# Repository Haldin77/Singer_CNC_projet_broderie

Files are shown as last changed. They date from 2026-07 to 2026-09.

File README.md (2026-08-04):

# Brodeuse CNC à partir d'une Singer en fonte

Conversion d'une machine à coudre Singer en fonte en brodeuse numérique : chariot X/Y sur mesure, axe Z motorisé pour l'entraînement de l'aiguille, contrôleur ESP32 sous FluidNC.

## L'idée qui structure le projet

La plupart des conversions DIY ([Embroiderino](https://gitlab.com/markol/embroiderino), [OpenEmbroidery](https://github.com/F33RNI/OpenEmbroidery)) gardent le moteur d'origine en boucle ouverte et doivent *suivre* la machine avec un capteur : l'électronique attend le signal « aiguille en haut » avant d'autoriser le mouvement du cadre.

**Ici, l'axe Z est piloté par le contrôleur.** On connaît donc l'angle de l'aiguille à tout instant en comptant les pas. Le capteur Hall ne sert plus qu'à l'indexation au démarrage et à la détection des pertes de pas.

Conséquence : un point de broderie s'écrit comme deux blocs G-code coordonnés.

```gcode
G1 X12.4 Y8.1 Z180    ; 1re demi-rotation : aiguille HAUTE, le cadre bouge
G1 Z360               ; 2e demi-rotation  : l'aiguille descend et pique
```

Z est un axe rotatif en degrés qui n'est jamais remis à zéro. C'est ce qui permet au planificateur de FluidNC de maintenir une rotation continue au lieu de s'arrêter à chaque point. **Aucun patch firmware n'est nécessaire** — ça tourne avec du FluidNC vanilla.

## État du projet

| Sous-ensemble | État |
|---|---|
| Post-processeur DST → G-code | ✅ fonctionnel, testé |
| Configuration FluidNC | ✅ écrite, non testée sur matériel |
| Schéma de câblage | ✅ [`docs/schema-cablage.svg`](docs/schema-cablage.svg) |
| Simulation Wokwi | ✅ brochage validé |
| **Mécanique** (portique X/Y + axe Z) | ✅ **montée et fonctionnelle** |
| Montage électrique | 🔧 en cours |
| Servo de tension du fil | 🔧 code prêt, servo à acheter |
| Alimentations | ✅ 48 V commandée + bloc 19,5 V récupéré |
| Détecteur de casse-fil | ❌ à concevoir |
| Pièces imprimées 3D | ❌ à modéliser |

## Architecture matérielle

| Axe | Moteur | Driver | Alimentation |
|---|---|---|---|
| Z (aiguille) | Nema 23, 3 N·m | DM542 | **48 V** — Mean Well LRS-100-48 |
| X | Nema 17 | DM320S | **19,5 V** — bloc HP récupéré |
| Y | **2 × Nema 17** (portique) | 2 × DM320S en parallèle | 19,5 V |
| A | Servo SG90/MG90S | PWM direct | 5 V |

Contrôleur : **ESP32-WROOM-32** + **74HCT245** (adaptation 3,3 V → 5 V pour les optocoupleurs des drivers). Pas de carte SD : les fichiers sont envoyés en **WiFi** via l'interface web de FluidNC.

## Organisation du dépôt

```
firmware/     Configuration FluidNC (YAML)
postproc/     Post-processeur broderie → G-code
  tests/      Fichiers DST de test
simulation/   Simulation Wokwi (validation du brochage)
gcode/        G-code généré
hardware/cad/ Pièces à imprimer (SolidWorks / STL)
docs/         Documentation détaillée + schéma de câblage
```

## Démarrage rapide

```bash
pip install pyembroidery
python3 postproc/dst2gcode.py motif.dst -o gcode/motif.nc --spm 400
```

Le script accepte DST, PES, EXP, JEF et les autres formats gérés par pyembroidery. Pour créer des motifs, [Ink/Stitch](https://inkstitch.org) (extension Inkscape, gratuite) exporte en DST.

## Chaîne complète

```
Inkscape + Ink/Stitch  →  motif.dst  →  dst2gcode.py  →  motif.nc  →  FluidNC (WiFi/SD)
```

## Documentation

- [**Montage électrique pas à pas**](docs/montage-electrique.md) — procédure avec test à chaque étape
- [Nomenclature et état des commandes](docs/nomenclature.md)
- [Câblage et brochage ESP32](docs/cablage.md)
- [Calculs et dimensionnement](docs/calculs.md)
- [Impression 3D](docs/impression-3d.md)
- [Mise en route et calibration](docs/mise-en-route.md)

## Avertissements

**Ne jamais mettre 48 V sur les DM320S.** Ils acceptent 12–38 V maximum et grillent au-delà. Les deux alimentations restent strictement séparées : 48 V uniquement vers le DM542, 19,5 V vers les trois DM320S. Seules les **masses** sont communes.

**Le pied à repriser n'est pas optionnel.** Avec un pied normal baissé, le tissu ne peut pas se déplacer. Relevé, le tissu remonte avec l'aiguille et les points sautent systématiquement. Il faut un pied à ressort qui suit la barre à aiguille, et les griffes d'entraînement abaissées.

## Licence

MIT — voir [LICENSE](LICENSE).

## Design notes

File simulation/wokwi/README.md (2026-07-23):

# Simulation Wokwi

Simulation du câblage logique de la brodeuse, avec un **vrai ESP32**, pour vérifier le brochage avant de toucher au matériel réel.

## Ouvrir la simulation

1. Aller sur [wokwi.com](https://wokwi.com) et créer un nouveau projet **ESP32 (Arduino)**
2. Remplacer le contenu de l'onglet `diagram.json` par celui de ce dossier
3. Remplacer le contenu de `sketch.ino` par celui de ce dossier
4. Cliquer sur ▶ pour lancer

Le moniteur série affiche l'état des quatre capteurs. Les trois moteurs tournent. Appuie sur les boutons pour simuler un capteur déclenché.

## Ce que la simulation représente fidèlement

- **ESP32** sur les mêmes GPIO de sortie que `firmware/fluidnc-config.yaml`
- Les **3 axes** (Z, X, Y) avec leurs signaux STEP / DIR et l'ENABLE partagé
- Les **4 entrées** capteur : fins de course X/Y, index Hall, casse-fil

## Ce qui diffère du montage réel — à garder en tête

| Simulation Wokwi | Machine réelle |
|---|---|
| Driver **A4988** | Driver **DM542 / DM320S** (Wokwi n'a pas ces modèles) |
| Pas de 74HCT245 | 74HCT245 obligatoire (décalage 3,3 V → 5 V) |
| Alimentation unique 5 V | **48 V** (Z) + **24 V** (X/Y) séparées |
| Code Arduino de test | **FluidNC** en production |

La simulation valide la **logique** (quel GPIO fait quoi), pas la **puissance**. Les A4988 remplacent les vrais drivers uniquement parce qu'ils partagent la même interface STEP/DIR/ENABLE.

## ⚠️ La leçon de cette simulation : le choix des pins d'entrée

La première version utilisait les **GPIO 34, 35, 36 et 39** pour les capteurs. Ce sont des pins en **entrée seule, sans pull-up interne** : ils flottent, et donnaient des lectures fantômes (un capteur à 0 sans qu'on l'ait touché). La directive `:pu` sur ces broches dans le YAML FluidNC est sans effet côté matériel.

**Deux façons de régler ça sur la vraie carte :**

1. **Pins à pull-up interne** (4, 21, 22, 32…) + `INPUT_PULLUP` — c'est le choix de cette simulation. Zéro composant externe, le plus simple.
2. **Garder 34-39** + résistances de tirage externes de 10 kΩ vers 3,3 V. Utile si on manque de pins ; souvent inutile car les modules capteurs (KY-003, cartes de fin de course) embarquent déjà leur pull-up.

👉 **Décision à reporter dans `firmware/fluidnc-config.yaml` et `docs/cablage.md`** : soit déplacer les entrées vers des pins à pull-up interne, soit assumer les résistances externes sur 34-39.

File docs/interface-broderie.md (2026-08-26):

# Interface broderie

Charger une image, la voir se transformer en points, l'envoyer à la machine et la broder — sans taper une seule commande.

## Lancer

```
cd interface
py -m pip install -r requirements.txt      (la première fois seulement)
py serveur.py
```

Puis `http://localhost:8080`. Depuis un téléphone ou une tablette sur le même réseau, remplace `localhost` par l'IP du PC.

Contrairement au mode couture, **cette interface a besoin d'un ordinateur** : le traitement d'image ne tient pas dans un ESP32. Le PC ne fait que préparer le fichier ; une fois la broderie lancée, il peut être éteint, la machine travaille seule depuis sa mémoire.

## Le déroulé

**1 · L'image.** Glisse un fichier dans la zone de dépôt.

**2 · Les réglages.** Taille visée, rendu, seuil de noir. Les réglages fins sont repliés — les valeurs par défaut conviennent dans la plupart des cas.

**3 · L'aperçu.** Le tracé réel des points : contour en bleu, remplissage en vert, sauts en pointillé orange. Le rectangle est ton champ de broderie. C'est ici qu'on juge, pas sur l'image de départ.

**4 · Broder.** Le bouton envoie le fichier dans la mémoire de la carte, fait le homing des trois axes, pose l'origine au centre du cadre et lance. Aucune coordonnée à saisir.

## Ce que la conversion sait faire, et ce qu'elle ne sait pas

Le moteur **binarise** l'image : chaque pixel est brodé ou ne l'est pas.

Sur un **logo, un dessin au trait, une silhouette, du texte**, c'est exactement ce qu'il faut. Les formes sont extraites, les trous respectés — l'intérieur d'un « O » reste vide — et chaque forme est remplie séparément.

Sur une **photographie**, tous les dégradés disparaissent et il ne reste qu'une tache informe. Rendre une photo demanderait des hachures de densité variable et un ordonnancement bien plus fin. Les logiciels commerciaux à plusieurs centaines d'euros s'y attellent avec des résultats inégaux.

## Les arrêts pendant la broderie

La machine s'arrête toute seule à plusieurs moments. Ce n'est pas une panne : chaque arrêt attend un geste de ta part, et tu reprends avec `~`.

| Quand | Ce que tu fais |
|---|---|
| Au premier point | tu remontes le fil de canette **à cet endroit**, tu tiens les deux fils vers l'arrière |
| Avant un saut de plus de 20 mm | tu **lèves le pied** |
| Juste après le saut | tu **rebaisses le pied** |
| À la fin | tu lèves le pied, puis tu dégages le cadre |

Le releveur de pied est manuel sur cette machine, et c'est lui qui écarte les disques de tension. Un long déplacement pied baissé tire sur le fil : il casse, ou il fronce le tissu.

Ces pauses disparaîtront quand le servo de débrayage (axe A) sera installé — c'est exactement le geste qu'il est censé automatiser.

Pour changer le seuil, ou les supprimer, voir `pause_saut_mm` dans `postproc/dst2gcode.py`.

### Le compteur de pauses

L'interface affiche le nombre de pauses que le motif imposera, à côté du nombre de points. C'est le chiffre à surveiller : il mesure le travail manuel, pas le travail de la machine. Au-delà de six, il vire à l'orange.

### Réduire les sauts

Le réglage **« relier les trajets distants de moins de X mm »** décide entre broder une liaison et sauter. Une liaison coûte quelques points, invisibles sous le remplissage ; un saut peut coûter une manipulation.

La liaison n'est acceptée que si le chemin **reste dans la matière** — sinon elle se verrait sur le tissu nu, et la machine saute.

Effet mesuré sur le mot SINGER en 120 mm :

| Distance de liaison | Trajets | Points |
|---|---|---|
| 0 mm — que des sauts | 136 | 2286 |
| 3 mm | 29 | 1971 |
| **5 mm — défaut** | **25** | **1967** |
| 8 mm | 24 | 1967 |

Cent trente-six trajets ramenés à vingt-cinq, **et** trois cents points de moins : les liaisons brodées remplacent des sauts qu'il fallait de toute façon rejoindre.

Au-delà de 5 mm le gain s'épuise, parce que les trajets encore séparés le sont par du vide, et le contrôle « reste dans la matière » refuse alors la liaison.

### Traverser en brodant plutôt que sauter

C'est le réglage qui supprime réellement les pauses.

Au lieu de **sauter** d'une zone à l'autre — aiguille en l'air, cadre qui file, fil tiré contre les disques de tension — la machine **y va en brodant**. Le fil est alors consommé par le releveur comme pour n'importe quel point : plus aucune traction, donc plus besoin de lever le pied.

Le prix, ce sont des fils tendus à couper à la fin. Mais **un saut en laissait déjà un**. La seule différence, c'est qu'il est maintenant piqué dans le tissu — et encadré par deux nœuds d'arrêt, donc le couper ne défait rien.

Sur SINGER en 120 mm :

| Traversée brodée jusqu'à | Points | Pauses | Fils à couper |
|---|---|---|---|
| 0 mm — que des sauts | 1983 | 4 | 0 |
| 15 mm | 2095 | 4 | 22 |
| **30 mm — défaut** | **2131** | **1** | **28** |
| 45 mm | 2138 | 0 | 29 |

Quatre pauses ramenées à une, pour 7 % de points en plus. À 45 mm, plus aucune pause.

Pourquoi les lettres produisent tant de trajets, au passage : une ligne horizontale traverse un `N` **trois fois** — montant gauche, diagonale, montant droit. Le `S`, le `E` et le `G` font pareil. Sur ce mot, 24 trajets de remplissage pour 6 lettres, et 7 contours parce que le `R` a un intérieur.

## Les nœuds d'arrêt

Avant chaque traversée, avant chaque saut et à la fin du motif, la machine pose un **petit zigzag** : trois points qui reculent d'un millimètre en se décalant d'un demi-millimètre alternativement de chaque côté, puis retour au point de départ. Quatre points en tout.

**Pourquoi un zigzag et pas un aller-retour.** Repasser exactement sur la même ligne fait retomber l'aiguille dans les mêmes trous. Le fil ne se bloque pas, il coulisse dans un trou agrandi, et le tissu s'affaiblit à cet endroit. En décalant, chaque point perce du tissu neuf et les fils se croisent — c'est le croisement qui tient, pas la répétition.

Mesuré sur un fichier réel, l'écart entre deux pénétrations successives d'un nœud est d'environ **1 mm**. Aucune ne retombe dans la précédente.

Ces valeurs — 3 points, 1 mm de long, 0,5 mm de large — sont celles des logiciels de numérisation du commerce. Réglables par `points_arret`, `longueur_arret_mm` et `largeur_arret_mm`.

**Le test qui tranche**, sur une chute : brode un petit motif, coupe les fils de traversée, puis tire franchement sur un bord. Si ça bouge, augmente `points_arret` à 4 ou `largeur_arret_mm` à 0,7.

## Le point de bourdon et les traits fins

C'est ce qui sépare un rendu amateur d'un rendu professionnel.

**Le problème.** Un trait de 1 mm rempli par des rangées parallèles donne trois rangées baveuses qui ne ressemblent plus au trait. C'est ce qui empâtait les logos au trait en petit format.

**Ce que font les professionnels.** Ils ne remplissent pas un trait fin : ils en prennent **l'axe** et le brodent en **point de bourdon** — un zigzag serré perpendiculaire au tracé, qui forme un ruban net et brillant.

La chaîne est donc :

```
masque → largeur locale → traits fins / masses pleines
                             ↓              ↓
                        squelette      remplissage
                             ↓              ↓
                          bourdon        contour
```

Le découpage se fait **à l'intérieur d'une même forme**, et c'est essentiel. Un logo est presque toujours d'un seul tenant : les contours au trait touchent les aplats. Classer la forme entière dans une famille faisait partir tout le dessin en bourdon, aplats compris — qui ressortaient confus. Le seuil ne donnait alors que deux résultats : une petite partie arbitraire en bourdon, ou la totalité.

La séparation se fait par **ouverture morphologique** : érosion puis dilatation par un disque du rayon voulu. Ne survivent que les endroits où ce disque tient entièrement — c'est exactement la définition d'une zone large. Le reste est du trait.

C'est ce que font les brodeurs professionnels : bourdon sur les traits, remplissage sur les aplats, sur la même pièce.

Vérifié sur un logo mixte d'un seul tenant — cadre fin, tête au trait, oreille pleine, rond plein, texte :

| | Résultat |
|---|---|
| Part en remplissage | 38 % |
| Part en bourdon | 62 % |
| Points | 2521 au lieu de 4394 |

Le ruban **épouse la largeur réelle du trait**, bornée entre 1,2 et 7 mm.

Mesuré sur un logo au trait à 160 mm :

| | Points | Durée |
|---|---|---|
| Remplissage seul | 3748 | 15,0 min |
| Avec bourdon | **2346** | **9,4 min** |

Plus net **et** plus rapide.

### Détails d'implémentation qui ont demandé du soin

**L'amincissement** est un Zhang-Suen écrit à la main : `cv2.ximgproc.thinning` n'existe que dans opencv-contrib, et scikit-image serait une dépendance de plus pour quarante lignes.

**Le traçage du squelette** ne compte pas les voisins mais les **transitions vide→matière** autour de chaque pixel. Dans une ligne d'un pixel en connexité 8, une marche d'escalier donne trois voisins à un pixel parfaitement ordinaire — compter ainsi fragmentait un simple anneau en trente-cinq morceaux.

**L'élagage** retire les barbules, ces courtes branches parasites que fait pousser l'amincissement sur le moindre bord irrégulier.

**Les tangentes sont lissées** sur un voisinage : sans cela la perpendiculaire bascule dans les angles et le ruban se vrille.

## La sous-couche

Une passe légère **avant** le remplissage : un contour en retrait de 0,7 mm, en point simple. Elle solidarise le tissu et l'entoilage et donne au remplissage une assise.

Sans elle, le remplissage tire sur un tissu libre — c'est la première cause de fronçage. Tous les motifs professionnels en ont une.

Les bourdons reçoivent la leur : une ligne centrale qui empêche le ruban de s'enfoncer et lui donne du relief.

L'ordre de broderie est celui du métier : **sous-couche, remplissage, bourdon, contour**.

## La compensation d'étirement

Le fil se contracte en se tendant et resserre la matière : une forme brodée sort plus étroite que dessinée. Les rubans sont élargis de 0,2 mm par défaut pour compenser, comme le font les logiciels du commerce.

## Le plancher physique

En dessous de **1,2 mm**, un trait ne peut pas exister : l'aiguille repique dans le trou précédent et **découpe le tissu** au lieu de le broder.

Deux mécanismes en découlent :

**L'épaississement.** Les traits sous ce minimum sont amenés à la largeur brodable, plutôt que de se désagréger. Seules les zones réellement trop fines sont dilatées.

**L'avertissement.** L'interface prévient quand des formes **fusionnent** en étant épaissies — elles étaient séparées de moins que la largeur minimale. C'est ce qui transforme un texte fin en pâte, et aucun réglage ne le rattrape : il faut agrandir le motif.

## Les réglages qui comptent

**Seuil de noir.** Laissé en automatique, il applique la méthode d'Otsu, qui se débrouille bien sur un dessin propre. Sur une image délavée ou photographiée de travers, décoche et déplace le curseur en regardant l'aperçu.

**Inverser.** Par défaut on brode ce qui est sombre. Un logo blanc sur fond noir demande cette case.

**Contour seul** donne un trait fin et un fichier dix fois plus léger. C'est le bon choix pour un premier essai sur un motif nouveau : quelques minutes au lieu d'une heure, et on voit tout de suite si la taille et le placement sont bons.

**Écartement du remplissage.** 0,45 mm donne un aplat dense. Monter à 0,8 divise le nombre de points par deux et laisse voir le tissu — parfois joli, souvent pas.

**Contour en triple passage.** Trois allers-retours sur le contour, ce qui triple son épaisseur apparente. C'est le « triple point » des brodeuses du commerce, et la façon la plus simple d'obtenir un trait visible sans calculer un point de bourdon.

## Les deux limites à surveiller

L'interface prévient d'elle-même, mais autant les connaître.

**La mémoire de l'ESP32.** C'est la contrainte dominante, et elle a demandé un travail à part — voir [Tenir dans la mémoire de l'ESP32](taille-fichiers.md). Le G-code est désormais écrit sous forme compacte, ce qui divise sa taille par deux. Ordres de grandeur, pour le mot SINGER :

| | Points | Taille |
|---|---|---|
| 120 mm, contour et remplissage | 1750 | 55 ko |
| 120 mm, écartement 1 mm | 1121 | 35 ko |
| 60 mm, contour et remplissage | 601 | 19 ko |
| 120 mm, contour seul | 663 | 20 ko |

**Le temps.** À 250 points/min, deux mille points font huit minutes. Un motif dense de quinze mille points fait une heure, pendant laquelle rien ne doit bouger.

## Si le téléversement automatique échoue

Le bouton **Télécharger le .nc** récupère le fichier. Tu le déposes ensuite dans le Flash Filesystem par le WebUI, comme tu l'as fait pour le YAML, puis tu le lances avec :

```
$LocalFS/Run=/motif.nc
```

Le fichier est de toute façon toujours écrit dans le dossier `gcode/` du projet.

## En ligne de commande

Tout le moteur est utilisable sans interface :

```
py postproc/image2points.py logo.png -o logo.nc --apercu logo.svg --largeur 100
```

`--mode contour` · `--seuil 140` · `--inverser` · `--espacement 0.8` · `--point 2.5` · `--spm 250`

## Comment c'est fait

```
image  →  seuillage  →  formes connexes
                              ├── contours  (OpenCV, simplifiés, triple passage)
                              └── remplissage (va-et-vient par forme)
                                        ↓
                              rééchantillonnage à la longueur de point
                                        ↓
                              ordonnancement au plus proche voisin
                                        ↓
                              dst2gcode.convert_paths()  →  G-code
```

La dernière étape réutilise **exactement le même émetteur** que pour les fichiers DST. Les demi-rotations de Z, le découpage des points trop longs, la remise à zéro de l'angle cumulé et les bornes du cadre sont donc traités de façon identique, quelle que soit la provenance du motif. Une correction à cet endroit profite aux deux chaînes.

Deux détails valent d'être signalés, parce qu'ils ont demandé une correction :

**Chaque forme est remplie séparément.** Sans ce découpage, le va-et-vient sautait d'une lettre à l'autre à chaque ligne — près de quatre cents sauts sur le mot SINGER au lieu de cent trente.

**Les liaisons entre lignes sont vérifiées.** Une liaison qui sortirait de la forme est refusée, et remplacée par un saut. C'est ce qui empêche le remplissage de traverser l'espace entre deux lettres, ou le trou d'un « O ».

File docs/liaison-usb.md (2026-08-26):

# Liaison USB et pédale progressive

Le WiFi sort de la boucle de commande. Le PC pilote la machine par un câble USB, et lit la pédale par un second.

```
pédale → potentiomètre → Arduino Uno ─USB→ PC ─USB→ ESP32 → drivers → machine
```

## Ce que ça règle d'un coup

| Problème | Pourquoi il disparaît |
|---|---|
| 44 ko de mémoire | le G-code reste sur le PC et part ligne par ligne |
| Déconnexions WiFi | le WiFi n'est plus dans la boucle de commande |
| Homing capricieux | plus d'émission radio soutenue pendant les commandes |
| Pas de pédale progressive | le PC lit le potentiomètre via l'Uno |

## Câblage du potentiomètre

Potentiomètre linéaire **10 kΩ**, solidaire mécaniquement de la course de la pédale.

| Borne | Vers |
|---|---|
| extrémité 1 | `5V` de l'Uno |
| curseur (milieu) | `A0` |
| extrémité 3 | `GND` |

Le 5 V ne pose aucun problème ici : l'ADC de l'Uno est prévu pour. C'est sur l'ESP32 qu'il serait destructeur.

> ⚠️ La pédale Singer d'origine commute du **230 V**. Elle doit être totalement déconnectée du secteur. Seul le potentiomètre, entraîné par sa course, est relié à l'Uno.

## Téléverser le croquis

Ouvre `pedale/pedale.ino` dans l'IDE Arduino, choisis la carte **Arduino Uno** et son port, puis téléverse.

Pour vérifier : ouvre le moniteur série à **115200 bauds**. Tu dois voir `PING` chaque seconde, et des lignes `P0` à `P100` quand tu bouges la pédale.

## Ce que le croquis fait

**Zone morte en début de course** — un potentiomètre ne revient jamais exactement à zéro, et une pédale au repos ne doit rien déclencher.

**Lissage** — le câble de la pédale passe près des drivers, qui rayonnent. Sans filtre, la consigne tremblerait en permanence.

**Un `PING` chaque seconde**, même à l'arrêt. C'est le cœur de la sécurité : il prouve que la pédale est toujours là. Si le PC cesse de le recevoir — câble débranché, Uno planté — il arrête la machine. Sans ce battement, une pédale muette serait indiscernable d'une pédale au repos.

**Le retour à zéro est transmis sans filtre.** C'est un ordre d'arrêt : il ne doit jamais être retenu par une hystérésis.

## Réponse de la pédale

Quadratique, comme sur une vraie machine : le début de course est fin — c'est là qu'on pose ses points un par un — et la fin de course monte vite.

| Enfoncement | Cadence |
|---|---|
| 3 % | 20 points/min |
| 30 % | 49 |
| 50 % | 109 |
| 70 % | 201 |
| 100 % | 400 |

Une réponse linéaire rendrait la machine impilotable au ralenti. Les constantes sont en haut de `interface/couture_pedale.py`.

## Le rythme d'envoi de la pédale

C'est le point qui a demandé deux corrections, et il mérite d'être compris.

**FluidNC répond `ok` dès qu'il a *planifié* un mouvement, pas quand il l'a exécuté.** Se caler sur les accusés de réception remplissait donc son planificateur de seize mouvements d'avance. Deux conséquences visibles : la machine continuait plusieurs secondes après le relâchement de la pédale, et elle cousait au ralenti — chaque mouvement décélérait à zéro faute du suivant prêt à temps.

Deuxième piège, plus subtil : envoyer « à 80 % de la durée d'un point » revient à envoyer **25 % plus vite que la machine ne consomme**. Le planificateur se remplit alors progressivement, et le délai revient au bout d'une minute de couture.

La solution est de raisonner en **avance de phase** : on garde un horizon — l'instant où tout ce qui est commandé sera terminé — et on n'envoie le point suivant que si cet horizon est à moins de 0,2 seconde. Le débit moyen se cale exactement sur la cadence, sans réglage.

Mesuré contre une machine simulée qui accuse vite et exécute au rythme réel :

| Pédale | Cadence visée | Cadence mesurée |
|---|---|---|
| 30 % | 49 pts/min | **49** |
| 60 % | 151 | **151** |
| 100 % | 400 | **400** |

Avance jamais supérieure à **1,5 point**. Au relâchement : **0 point envoyé de plus**, arrêt effectif en **0,21 s** — le temps de finir le point en cours, aiguille ressortie. C'est exactement le comportement d'une machine à coudre.

## Le contrôle de flux

L'envoi se fait par **comptage de caractères** : on garde en vol juste assez de lignes pour remplir le tampon de réception de la carte — 127 octets — sans jamais le déborder.

C'est supérieur à l'envoi « une ligne, un ok » : le tampon reste alimenté, donc la machine ne marque pas de micro-arrêt entre les points. Mesuré sur le banc : **119 octets au maximum sur 127**, jamais dépassé.

## Sécurité

**En broderie**, si l'envoi s'interrompt, la machine s'arrête faute de lignes. Rien ne part tout seul.

**En couture**, l'arbre avance par salves de deux points, chacune lancée à la vitesse lue sur la pédale à cet instant. Si quoi que ce soit s'interrompt, la machine termine sa salve et s'arrête. Elle n'attend **aucun** ordre d'arrêt qui pourrait ne jamais arriver — c'est un homme-mort par construction.

## Le banc d'essai

```
cd interface
python tests/test_liaison.py
```

Il crée un faux FluidNC et un faux Arduino sur des ports virtuels, et fait tourner le vrai code contre eux. Aucun matériel nécessaire.

Il vérifie que le tampon ne déborde jamais, que toutes les lignes arrivent dans l'ordre, qu'un `M0` suspend bien l'envoi jusqu'à la reprise, que pause et annulation passent en temps réel hors file d'attente, et qu'une pédale muette rend zéro.

Le faux firmware utilise **deux threads**, comme le vrai : un pour la lecture, un pour l'exécution. Un simulateur mono-thread se bloque sur le `M0` et ne voit jamais le `~` censé le débloquer — ce qui illustre précisément pourquoi le vrai firmware traite les caractères temps réel à part.

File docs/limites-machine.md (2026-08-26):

# Limites de course — mesures et champ de broderie

Mesuré le 5 août 2026, après validation du homing des trois axes.

## Méthode

Homing complet, puis `soft_limits` désactivé temporairement, puis avance par paliers décroissants jusqu'à la butée mécanique. Position lue avec `?`.

```
$H
$/axes/x/soft_limits=false
$/axes/y/soft_limits=false
$J=G91 X20 F500      (répété, puis X5, puis X1)
?
```

## Résultats

| Axe | Butée atteinte | Marge retirée | `max_travel_mm` |
|---|---|---|---|
| X | 172,000 mm | 3 mm | **169,000** |
| Y | 121,000 mm | 3 mm | **118,000** |
| Z | rotatif | — | 720,000 (garde-fou de homing seulement) |

La marge de 3 mm évite que le chariot vienne taper la structure sur une accumulation d'erreurs ou un léger décalage du capteur d'origine.

## Dégagements après homing (`pulloff_mm`)

| Axe | Capteur | `pulloff_mm` | Pourquoi |
|---|---|---|---|
| X | microrupteur à levier | 2,000 | valeur d'origine, jamais mise en défaut |
| Y | microrupteur à levier | **5,000** | 2 mm laissaient le levier enfoncé → `ALARM:8` |
| Z | Hall A3144 + aimant | **10,000** (degrés) | 5° laissaient l'aimant dans le champ → `ALARM:8` |

`ALARM:8 Homing Fail Pulloff` signifie toujours la même chose : après le dégagement, le capteur est encore actionné. La réponse est d'augmenter cette valeur, jamais de toucher aux vitesses.

Sur Z, augmenter le dégagement **ne décale pas la phase de l'aiguille** : le zéro machine reste ancré sur le déclenchement du capteur, et les `Z180` / `Z360` du G-code sont des positions absolues.

## Ce que ça change

Le champ utile est de **169 × 118 mm**. C'est **Y qui bride la machine**, et l'écart avec l'hypothèse de départ est important : on avait tablé sur 180 mm en Y, il y en a 121.

Conséquence directe : **le cadre Brother SA444 (130 × 180) ne rentre pas**, ni dans un sens ni dans l'autre. En le tournant de 90°, il faudrait 180 mm en X et on n'en a que 169.

Le post-processeur a donc été recalé sur **165 × 114 mm** (`--hoop`), soit le champ mesuré moins 2 mm de chaque côté. Cela correspond à un cadre du commerce de type 160 × 110, très courant.

## Si tu veux récupérer de la course en Y

Trois pistes, par ordre de gain :

1. **Repositionner le microrupteur d'origine Y.** S'il est monté en retrait, chaque millimètre récupéré est un millimètre de champ. Vérifie aussi que le `pulloff_mm` de 5 mm n'est pas surdimensionné une fois le capteur bien placé.
2. **Vérifier ce qui limite mécaniquement l'autre extrémité.** Une équerre, un passage de câble ou une vis dépassant coûtent parfois 10 à 15 mm pour rien.
3. **Rallonger le rail Y.** C'est le seul vrai gain, mais cela suppose de refaire la traverse.

## Z : pourquoi 720 et pas 10 000 000

`soft_limits` est à `false` sur Z, donc `max_travel_mm` ne limite pas la rotation de l'arbre — l'axe peut tourner indéfiniment pendant la broderie.

Cette valeur sert uniquement de **distance maximale de recherche pendant le homing**. Avec 720° (deux tours d'arbre), si l'aimant passe devant le capteur Hall sans être détecté, FluidNC lève une alarme au bout de deux tours. Avec l'ancienne valeur, l'arbre aurait tourné des heures.

## Vérification

Après téléversement et `$Bye` :

```
$H
$J=G91 X500 F500
```

Doit être refusé (`error:15`) ou tronqué à la limite. Idem en Y.

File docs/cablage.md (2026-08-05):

# Câblage et brochage

## Les schémas

Quatre schémas, un par sous-ensemble. Chacun tient sur un écran et se lit sans se perdre dans les fils.

| Schéma | Contenu |
|---|---|
| [1 · Alimentations](schema-1-alimentations.svg) | arrivée 230 V, interrupteur bipolaire, fusible, terre de protection, les trois alimentations, le condensateur |
| [2 · ESP32 → 74HCT245](schema-2-logique.svg) | brochage réel du boîtier DIP-20, entrées A, sorties B, et les trois broches de service qu'on oublie |
| [3 · Drivers et moteurs](schema-3-puissance.svg) | les quatre drivers borne par borne, et le raccordement des bobines |
| [4 · Capteurs](schema-4-capteurs.svg) | principe du pull-up interne, fins de course, arrêt d'urgence, capteurs Hall, servo |

Et la [**table de câblage**](table-cablage.md) : chaque fil du montage, avec origine, destination, section et couleur. C'est elle qu'il faut avoir sous les yeux avec le fer à souder — les schémas servent à comprendre, la table à exécuter.

## La carte de commande

Deux versions du même circuit, à faire dans cet ordre.

**D'abord sans soudure**, pour valider la chaîne complète :

- [**Montage sur platine d'essai**](montage-platine-essai.md) — pas à pas, avec le [plan](plan-platine-essai.svg)

**Ensuite en version définitive**, une fois que la machine brode. Une platine d'essai tient par friction et ne survit pas aux vibrations :

- [**Plan d'implantation sur plaque perforée**](plan-implantation-plaque.svg) — placement des composants trou par trou
- [**Liaisons trou par trou**](plaque-liaisons.md) — les 34 fils, l'ordre de montage et les vérifications au multimètre

Le circuit est strictement identique dans les deux cas.

Le symbole de masse ⏚ désigne le **0 V logique**. Attention, il existe un second réseau : le **0 V puissance**, celui des « − » des alimentations et des bornes `GND` des drivers. Les optocoupleurs des drivers isolent les deux — ils n'ont pas besoin d'être reliés.

> **État actuel du montage.** Le détecteur de casse-fil, l'arrêt d'urgence et le servo de tension ne sont pas encore installés : ils sont commentés dans `fluidnc-config.yaml`, et le post-processeur n'émet plus de commandes d'axe A par défaut. La machine tourne en 3 axes. Les schémas ci-dessous montrent la cible complète.

> Les vues d'ensemble [`schema-cablage.svg`](schema-cablage.svg) et [`schema-electronique-complet.svg`](schema-electronique-complet.svg) restent dans le dépôt, mais elles sont denses. Préfère les quatre schémas ci-dessus pour le montage.

## Architecture

```
   Secteur
      │
      ├── Alim 48 V ────► DM542 ──────► Nema 23 (axe Z)
      │   (LRS-100-48)
      │
      ├── Alim 19,5 V ─┬─► DM320S ─────► Nema 17 (axe X)
      │    (bloc HP    ├─► DM320S ─────► Nema 17 (axe Y gauche)
      │     récupéré)  └─► DM320S ─────► Nema 17 (axe Y droite)
      │
      └── USB 5 V ───────► ESP32 + 74HCT245
                              │
                              └── signaux step/dir/enable en 5 V
```

⚠️ **Alimentation du contrôleur séparée de celle des moteurs.** Une alimentation commune court-circuite l'isolation galvanique des optocoupleurs. Avec un Nema 23 qui commute 4,2 A sous 48 V, le bruit se propagerait directement dans l'ESP32.

## Pourquoi le 74HCT245

L'ESP32 sort en **3,3 V**. Les entrées des DM542/DM320S sont optocouplées et dimensionnées pour du **5 V** : leur résistance interne est calculée pour tirer ~15 mA sous 5 V. En 3,3 V, le courant tombe à ~2 mA — sous le seuil fiable de déclenchement.

Le 74HCT245 résout les deux problèmes à la fois :

- famille **HCT** → seuil d'entrée à 2,0 V, donc 3,3 V est lu comme un HIGH franc
- sortie garantie **4,4 V minimum**
- **35 mA par canal** en source ou en sink, largement de quoi alimenter les optos

⚠️ Prendre du **74HCT245**, pas du 74HC245. Le HC a un seuil à 3,15 V : les 3,3 V de l'ESP32 passeraient tout juste, ça marcherait sur l'établi et lâcherait au milieu d'une broderie.

### Câblage du 74HCT245 (DIP-20)

| Broche | Signal | Raccordement |
|---|---|---|
| 1 | DIR | **+5 V** (sens A → B) |
| 2–9 | A1–A8 | entrées, depuis l'ESP32 |
| 10 | GND | masse |
| 11–18 | B8–B1 | sorties, vers les drivers |
| 19 | OE | **GND** (sorties actives) |
| 20 | VCC | +5 V |

## Brochage ESP32 (38 broches)

### Sorties vers les drivers (via 74HCT245)

Le portique Y a **deux moteurs** (un de chaque côté), donc **quatre drivers** au total. Les deux drivers Y reçoivent les **mêmes signaux**, câblés en parallèle.

| Signal | GPIO | Canal 245 | Destination |
|---|---|---|---|
| X step | 26 | A1 → B1 | DM320S X, PUL+ |
| X dir | 16 | A2 → B2 | DM320S X, DIR+ |
| Y step | 25 | A3 → B3 | **DM320S Y1 + Y2**, PUL+ (parallèle) |
| Y dir | 27 | A4 → B4 | **DM320S Y1 + Y2**, DIR+ (parallèle) |
| Z step | 17 | A5 → B5 | DM542, PUL+ |
| Z dir | 14 | A6 → B6 | DM542, DIR+ |
| ENABLE X + Z | 13 | A7 → B7 | ENA+ de X et Z |
| ENABLE Y1 + Y2 | 13 | A8 → B8 | ENA+ de Y1 et Y2 |

Les broches `PUL−`, `DIR−` et `ENA−` de tous les drivers vont à la **masse commune**.

⚠️ **Pourquoi l'ENABLE est réparti sur deux canaux (B7 et B8).** Chaque entrée d'opto tire ~10–15 mA, et le 74HCT245 fournit 35 mA max par sortie. Avec 4 drivers, un seul canal ENABLE dépasserait (~40–60 mA). On alimente donc les canaux A7 et A8 depuis le **même GPIO 13**, et on répartit les 4 ENA+ en deux paires. Idem, prudence, sur Y step/dir : chaque canal pilote 2 optos (~30 mA), c'est dans les clous.

### Entrées

| Signal | GPIO | Note |
|---|---|---|
| Fin de course X | 4 | pull-up interne activé (`:pu`) |
| Fin de course Y | 21 | pull-up interne activé |
| Capteur Hall (index Z) | 22 | KY-003, collecteur ouvert |
| Détecteur casse-fil | 32 | câblé en *feed hold* |
| Arrêt d'urgence | 33 | câblé en *reset*, bouton vers GND |

Reprise (*cycle start*) : via l'interface web FluidNC, pas de bouton dédié.

⚠️ **Pourquoi pas les GPIO 34–39 ?** Ils sont en entrée seule et **sans pull-up interne** : ils flottent et donnent des lectures fantômes (constaté en simulation Wokwi). Les utiliser exigerait des résistances externes de 10 kΩ vers 3,3 V. Les GPIO 4/21/22/32/33 ont un pull-up interne : capteur câblé en deux fils (signal + masse), zéro composant.

### Combien de fins de course faut-il ?

**Deux sont indispensables** : X sur GPIO 4, Y sur GPIO 21. Ce ne sont pas des sécurités mais les **références d'origine** de la machine. Le YAML impose `must_home: true` — sans elles, FluidNC refuse tout mouvement, et un motif brodé n'aurait aucun repère commun d'une session à l'autre.

Un seul capteur suffit pour Y, même avec deux moteurs : ils sont mécaniquement solidaires du portique et bougent ensemble.

L'axe Z n'a pas de fin de course mécanique, mais un **capteur Hall** (GPIO 22) qui indexe l'aiguille au point mort haut. C'est le même rôle : donner une origine.

**Les capteurs en trop ne sont pas inutiles.** Trois usages, par ordre d'intérêt :

1. **Rechange.** Un microrupteur de fin de course finit par s'user ou se dérégler. En avoir deux d'avance évite d'arrêter le projet pour une pièce à 1 €.

2. **Butée de fin de course opposée.** Chaque axe n'est protégé que d'un côté. Un second capteur à l'autre extrémité déclenche une alarme si le chariot déborde. Utile pendant la mise au point, quand `steps_per_mm` ou `max_travel_mm` sont encore approximatifs.

3. **Doubler le capteur Y.** Avec un capteur par côté du portique, FluidNC peut détecter qu'il s'est mis en biais (`squaring`). C'est un raffinement, pas une nécessité sur une course de 180 mm.

Pour l'usage 2, deux montages possibles :

| Montage | Câblage | Limite |
|---|---|---|
| Un GPIO par capteur | GPIO 19 et 23 (libérés par l'abandon du SD) | consomme des broches |
| Les deux en parallèle sur un GPIO | contacts NO reliés au même fil | FluidNC ne sait pas lequel a déclenché |

Les contacts NO en parallèle fonctionnent bien : n'importe lequel qui se ferme tire la broche à la masse. Utiliser `limit_all_pin` dans le YAML plutôt que `limit_neg_pin`.

⚠️ Éviter **GPIO 5** pour cet usage : c'est une broche de strapping. Un capteur actionné au moment du démarrage empêcherait la carte de booter. GPIO 19 et 23 n'ont pas ce défaut.

⚠️ **Contacts NO, pas NC.** Un microrupteur câblé en normalement fermé maintient la broche à la masse en permanence — sur GPIO 33 cela provoque le fameux « reset loop ». Vérifie chaque capteur au multimètre avant de le monter : relâché = circuit ouvert, actionné = continuité.

### Servo de débrayage de la tension du fil (axe A)

| Signal | GPIO | Note |
|---|---|---|
| Servo PWM | 18 | signal 3,3 V direct, servo alimenté en 5 V |

Un petit servo (SG90 ou MG90S) pousse la **tige de débrayage des disques de tension** de la Singer. Pendant un saut long, le post-processeur relâche la tension (`G0 A90`) pour que le fil se dévide sans casser ni tirer le tissu, puis la ré-engage (`G0 A0`).

- **Alimentation : le 5 V, pas le 3,3 V.** Un servo tire 100–250 mA en mouvement, trop pour la sortie 3,3 V de l'ESP32. Fil rouge → 5 V, fil noir → masse commune, fil signal → GPIO 18.
- Le signal 3,3 V est accepté par la plupart des servos. Si le tien est capricieux, passe-le par un canal libre du 74HCT245.

### Pas de carte SD — on brode en WiFi

Le lecteur SD est abandonné : on envoie les fichiers G-code via l'interface web de FluidNC. Ça libère les GPIO 5, 18, 19, 23 — dont le **18 sert maintenant au servo**.

Configuration WiFi (par commandes, une fois FluidNC flashé) :

```
$Sta/SSID=MonReseau
$Sta/Password=MonMotDePasse
$WiFi/Mode=STA
```

## Broches à éviter

| GPIO | Problème |
|---|---|
| 0, 2, 12, 15 | broches de strapping — un mauvais niveau au reset empêche le démarrage |
| 1, 3 | UART0, utilisé par le port USB série |
| 6–11 | reliées à la flash interne, inutilisables |

## Réglages des drivers

### DM542 (axe Z)

| Réglage | Valeur | Raison |
|---|---|---|
| Microstepping | **1/4** (800 pas/tour) | à 400 pts/min et 2:1 → 10 700 pas/s. En 1/16 ce serait 42 700 pas/s |
| Courant | **4,2 A** | correspond au Nema 23 de 3 N·m |
| Tension | **48 V** | indispensable au couple en vitesse |

### DM320S (axes X/Y)

| Réglage | Valeur | Raison |
|---|---|---|
| Microstepping | **1/16** (3200 pas/tour) | 80 pas/mm → résolution 0,0125 mm |
| Courant | selon les Nema 17 | typiquement 1,2–1,7 A |
| Tension | **19,5 V** (bloc HP) | plage driver 12–38 V. ⚠️ jamais plus de 38 V |

Le 19,5 V ne bride pas la vitesse : à 120 mm/s (180 tr/min), inverser le courant demande 0,52 ms alors que la demi-période en offre 3,33 — **6× de marge**.

⚠️ **Condensateur 1000 µF / 35 V** en parallèle sur la sortie du bloc HP, au plus près des drivers. Les alimentations de PC portable supportent mal l'énergie renvoyée par les moteurs en décélération (BEMF) et peuvent couper. Respecter la polarité : bande blanche vers le −.

## Détecteur de casse-fil

Une roue libre montée sur le trajet du fil, avec un aimant collé dans sa jante et un capteur Hall en regard. Le fil défile → la roue tourne → le capteur émet des impulsions.

Si aucune impulsion n'arrive pendant 5 ou 6 points consécutifs, c'est que le fil est cassé ou que la canette est vide : le firmware met en pause via l'entrée *feed hold*.

Sans ce détecteur, une casse de fil se traduit par plusieurs milliers de points brodés dans le vide, et surtout par la difficulté de retrouver le point exact où reprendre.

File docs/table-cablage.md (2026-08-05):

# Table de câblage — fil par fil

Chaque ligne est **un fil à sertir**. Coche au fur et à mesure : c'est la façon la plus sûre de ne rien oublier et de ne rien brancher deux fois.

Les schémas correspondants :

- [1 · Alimentations](schema-1-alimentations.svg)
- [2 · ESP32 → 74HCT245](schema-2-logique.svg)
- [3 · Drivers et moteurs](schema-3-puissance.svg)
- [4 · Capteurs, arrêt d'urgence et servo](schema-4-capteurs.svg)

> ⚠️ **Il y a deux réseaux de 0 V distincts**, et il ne faut pas les confondre :
>
> - **0 V logique** — l'ESP32, le 74HCT245, les capteurs, et les bornes `PUL−` `DIR−` `ENA−` des drivers
> - **0 V puissance** — les « − » du 48 V et du 19,5 V, et les bornes `GND` des drivers
>
> Les optocoupleurs des drivers isolent ces deux réseaux. Voir le dernier tableau.

---

## 1 · Secteur 230 V

⚠️ Hors tension, prise débranchée. Bornes couvertes avant la mise sous tension.

| # | De | Vers | Section | Couleur |
|---|---|---|---|---|
| 1.1 | Prise 230 V — phase | Interrupteur bipolaire, entrée 1 | 1,5 mm² | marron |
| 1.2 | Prise 230 V — neutre | Interrupteur bipolaire, entrée 2 | 1,5 mm² | bleu |
| 1.3 | Prise 230 V — terre | Bornier de terre | 1,5 mm² | vert/jaune |
| 1.4 | Interrupteur, sortie 1 | Fusible T 2 A, entrée | 1,5 mm² | marron |
| 1.5 | Fusible, sortie | Mean Well 48 V — L | 1 mm² | marron |
| 1.6 | Fusible, sortie | Bloc HP 19,5 V — L | 1 mm² | marron |
| 1.7 | Fusible, sortie | Chargeur USB — L | 1 mm² | marron |
| 1.8 | Interrupteur, sortie 2 | Mean Well 48 V — N | 1 mm² | bleu |
| 1.9 | Interrupteur, sortie 2 | Bloc HP 19,5 V — N | 1 mm² | bleu |
| 1.10 | Interrupteur, sortie 2 | Chargeur USB — N | 1 mm² | bleu |
| 1.11 | Bornier de terre | Mean Well — borne PE | 1,5 mm² | vert/jaune |
| 1.12 | Bornier de terre | Châssis métallique | 1,5 mm² | vert/jaune |
| 1.13 | Bornier de terre | Bâti de la Singer | 1,5 mm² | vert/jaune |

L'interrupteur doit couper **la phase et le neutre**. Le fusible temporisé (T) supporte le pic d'appel des alimentations à découpage.

---

## 2 · Sorties des alimentations

| # | De | Vers | Section | Couleur |
|---|---|---|---|---|
| 2.1 | Mean Well V+ | DM542 (Z) — VCC | 0,75 mm² | rouge |
| 2.2 | Mean Well V− | 0 V puissance | 0,75 mm² | noir |
| 2.3 | Bloc HP + | DM320S X — VCC | 0,75 mm² | rouge |
| 2.4 | Bloc HP + | DM320S Y1 — VCC | 0,75 mm² | rouge |
| 2.5 | Bloc HP + | DM320S Y2 — VCC | 0,75 mm² | rouge |
| 2.6 | Bloc HP + | Condensateur 1000 µF / 35 V, borne + | 0,75 mm² | rouge |
| 2.7 | Bloc HP − | 0 V puissance | 0,75 mm² | noir |
| 2.8 | Condensateur, borne − | 0 V puissance | 0,75 mm² | noir |
| 2.9 | ESP32 — broche 5V | 74HCT245 broche 20 (VCC) | 0,25 mm² | rouge |
| 2.10 | ESP32 — broche 5V | 74HCT245 broche 1 (DIR) | 0,25 mm² | rouge |
| 2.11 | ESP32 — broche GND | 0 V logique | 0,5 mm² | noir |

Le condensateur se monte **au plus près des drivers**, bande blanche (borne −) côté masse. Les alimentations de PC portable coupent facilement sur l'énergie renvoyée par les moteurs en décélération.

⚠️ Le 48 V ne va **que** sur le DM542. Une inversion détruit les trois DM320S d'un coup.

---

## 3 · ESP32 → 74HCT245 (côté A)

Fils courts, torsadés si possible. Section 0,14 à 0,25 mm².

| # | ESP32 | 74HCT245 | Signal |
|---|---|---|---|
| 3.1 | GPIO 26 | broche 2 (A1) | X step |
| 3.2 | GPIO 16 | broche 3 (A2) | X dir |
| 3.3 | GPIO 25 | broche 4 (A3) | Y step |
| 3.4 | GPIO 27 | broche 5 (A4) | Y dir |
| 3.5 | GPIO 17 | broche 6 (A5) | Z step |
| 3.6 | GPIO 14 | broche 7 (A6) | Z dir |
| 3.7 | GPIO 13 | broche 8 (A7) | enable X et Z |
| 3.8 | GPIO 13 | broche 9 (A8) | enable Y1 et Y2 |

Les lignes 3.7 et 3.8 partent bien du **même** GPIO 13 : un seul canal ne fournirait pas les ~50 mA que réclament quatre optocoupleurs.

## 3 bis · Les trois broches de service du 245

| # | 74HCT245 | Vers | Rôle |
|---|---|---|---|
| 3.9 | broche 20 (VCC) | +5 V | alimentation |
| 3.10 | broche 1 (DIR) | +5 V | sens de transfert A → B |
| 3.11 | broche 19 (OE) | 0 V logique | active les sorties |
| 3.12 | broche 10 (GND) | 0 V logique | masse |

**Si rien ne bouge nulle part, c'est ici.** Un DIR en l'air ou un OE non relié rend la puce muette, sans le moindre message d'erreur.

---

## 4 · 74HCT245 → drivers (côté B)

| # | 74HCT245 | Vers | Signal |
|---|---|---|---|
| 4.1 | broche 18 (B1) | DM320S X — PUL+ | X step |
| 4.2 | broche 17 (B2) | DM320S X — DIR+ | X dir |
| 4.3 | broche 16 (B3) | DM320S Y1 — PUL+ | Y step |
| 4.4 | broche 16 (B3) | DM320S Y2 — PUL+ | Y step (parallèle) |
| 4.5 | broche 15 (B4) | DM320S Y1 — DIR+ | Y dir |
| 4.6 | broche 15 (B4) | DM320S Y2 — DIR+ | Y dir (parallèle) |
| 4.7 | broche 14 (B5) | DM542 Z — PUL+ | Z step |
| 4.8 | broche 13 (B6) | DM542 Z — DIR+ | Z dir |
| 4.9 | broche 12 (B7) | DM320S X — ENA+ | enable |
| 4.10 | broche 12 (B7) | DM542 Z — ENA+ | enable |
| 4.11 | broche 11 (B8) | DM320S Y1 — ENA+ | enable |
| 4.12 | broche 11 (B8) | DM320S Y2 — ENA+ | enable |

---

## 5 · Retours des drivers

Attention : **deux destinations différentes** selon la borne.

Les bornes `PUL−` `DIR−` `ENA−` sont du côté « entrée » de l'optocoupleur. Elles referment la boucle du signal et retournent au **0 V logique**, celui de la carte.

La borne `GND` est du côté « puissance ». Elle retourne au **« − » de l'alimentation du driver**, directement, sans passer par la carte.

| # | De | Vers | Section |
|---|---|---|---|
| 5.1 – 5.3 | DM320S X — PUL−, DIR−, ENA− | 0 V **logique** (J1) | 0,25 mm² |
| 5.4 | DM320S X — GND | « − » du bloc HP 19,5 V | 0,75 mm² |
| 5.5 – 5.7 | DM320S Y1 — PUL−, DIR−, ENA− | 0 V **logique** (J1) | 0,25 mm² |
| 5.8 | DM320S Y1 — GND | « − » du bloc HP 19,5 V | 0,75 mm² |
| 5.9 – 5.11 | DM320S Y2 — PUL−, DIR−, ENA− | 0 V **logique** (J1) | 0,25 mm² |
| 5.12 | DM320S Y2 — GND | « − » du bloc HP 19,5 V | 0,75 mm² |
| 5.13 – 5.15 | DM542 Z — PUL−, DIR−, ENA− | 0 V **logique** (J1) | 0,25 mm² |
| 5.16 | DM542 Z — GND | « − » de la Mean Well 48 V | 0,75 mm² |

C'est aussi ce qui explique les sections différentes : les retours de signal transportent 15 mA, les retours de puissance jusqu'à 2 A.

---

## 6 · Drivers → moteurs

**Repérer les paires au multimètre avant de brancher.** Deux fils entre lesquels on mesure une faible résistance appartiennent à la même bobine.

| # | Driver | Moteur | Section |
|---|---|---|---|
| 6.1 | DM320S X — A+, A−, B+, B− | Nema 17 X | 0,5 mm² |
| 6.2 | DM320S Y1 — A+, A−, B+, B− | Nema 17 Y gauche | 0,5 mm² |
| 6.3 | DM320S Y2 — A+, A−, B+, B− | Nema 17 Y droite | 0,5 mm² |
| 6.4 | DM542 Z — A+, A−, B+, B− | Nema 23 axe Z | 0,75 mm² |

Résistances de bobine attendues : **2,6 Ω** sur les Nema 17, **0,9 Ω** sur le Nema 23. Entre deux bobines différentes : circuit ouvert.

⚠️ Ne jamais débrancher un moteur alors que son driver est sous tension.

---

## 7 · Capteurs, arrêt d'urgence et servo

> **Pour l'instant, seules les lignes 7.1 à 7.4 et 7.7 à 7.9 sont à câbler.** Le détecteur de casse-fil, l'arrêt d'urgence et le servo ne sont pas encore installés, et leurs entrées sont commentées dans `fluidnc-config.yaml`. Les GPIO 18, 32 et 33 restent libres.
>
> ⚠️ Ne déclare jamais une entrée dans le YAML avant d'avoir câblé son capteur : une broche déclarée mais laissée en l'air capte le bruit des drivers et se déclenche toute seule.

| # | De | Vers | Fils |
|---|---|---|---|
| 7.1 | Fin de course X — contact 1 | ESP32 GPIO 4 | 2 |
| 7.2 | Fin de course X — contact 2 | 0 V logique | |
| 7.3 | Fin de course Y — contact 1 | ESP32 GPIO 21 | 2 |
| 7.4 | Fin de course Y — contact 2 | 0 V logique | |
| 7.5 | Arrêt d'urgence — contact 1 | ESP32 GPIO 33 | *à venir* |
| 7.6 | Arrêt d'urgence — contact 2 | 0 V logique | *à venir* |
| 7.7 | Hall index Z (KY-003) — OUT | ESP32 GPIO 22 | 3 |
| 7.8 | Hall index Z — VCC | +5 V | |
| 7.9 | Hall index Z — GND | 0 V logique | |
| 7.10 | Casse-fil (Hall) — OUT | ESP32 GPIO 32 | *à venir* |
| 7.11 | Casse-fil — VCC | +5 V | |
| 7.12 | Casse-fil — GND | 0 V logique | |
| 7.13 | Servo — signal (orange) | ESP32 GPIO 18 | *à venir* |
| 7.14 | Servo — + (rouge) | +5 V | |
| 7.15 | Servo — masse (marron) | 0 V logique | |

Les contacts sont **normalement ouverts**. À vérifier au multimètre avant montage : relâché = circuit ouvert, actionné = continuité.

Le servo se raccorde au **5 V**, jamais au 3,3 V : il tire 100 à 250 mA en mouvement.

---

## 8 · Les deux réseaux de 0 V

### 0 V logique — la barre de la carte

C'est le bus en fil nu de la plaque perforée. Tout y arrive en étoile.

| Origine | Nombre de fils |
|---|---|
| ESP32 — GND | 1 |
| 74HCT245 — broches 10 et 19 | 2 |
| Drivers — PUL−, DIR−, ENA− | 12 |
| Capteurs et servo | 5 |

Sans lui, la boucle du signal est ouverte : le courant qui traverse la LED de l'optocoupleur n'a pas de chemin de retour, et le driver ne voit rien.

### 0 V puissance — au bornier des alimentations

| Origine | Nombre de fils |
|---|---|
| Mean Well 48 V — V− | 1 |
| Bloc HP 19,5 V — − | 1 |
| Condensateur 1000 µF — − | 1 |
| Drivers — GND | 4 |

### Faut-il relier les deux ?

**Non, ce n'est pas nécessaire.** Les entrées des DM320S et du DM542 sont optocouplées : elles sont galvaniquement isolées de la partie puissance du driver. C'est précisément ce pour quoi cette isolation existe, et la garder évite que le bruit de commutation des moteurs ne remonte sur la référence des signaux.

Si tu constates un jour des comportements erratiques, tu pourras les relier — mais alors **en un seul point**, jamais deux, sous peine de créer une boucle de masse.

⚠️ Les « + », eux, ne se rencontrent jamais. Le 48 V ne doit toucher ni le 19,5 V ni le 5 V.

La **terre de protection** est encore une autre chose : elle protège les personnes, va sur les carcasses métalliques, et n'a de lien ni avec l'un ni avec l'autre de ces réseaux.

---

## Vérifications avant la première mise sous tension

| Vérification | Attendu |
|---|---|
| Continuité entre les « − » du 48 V et du 19,5 V | continuité |
| Continuité entre le 0 V logique et le 0 V puissance | circuit ouvert (normal) |
| Continuité entre 48 V+ et 19,5 V+ | **circuit ouvert** |
| Continuité entre chaque « + » et la masse | **circuit ouvert** |
| Continuité GPIO 33 ↔ masse, bouton relâché | **circuit ouvert** |
| Polarité du condensateur | bande blanche côté masse |
| Marquage de la puce | `74HCT245`, avec le T |
| Micro-interrupteurs des trois DM320S | réglages identiques |

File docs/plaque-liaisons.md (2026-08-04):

# Carte de commande — liaisons trou par trou

Compagnon du [plan d'implantation](plan-implantation-plaque.svg). Chaque ligne est **un fil à souder au dos de la plaque**, en fil isolé souple.

Les coordonnées se lisent **(colonne, rangée)**, comptées depuis le coin haut-gauche de la zone utile. Les repères tous les 5 trous sont marqués sur le plan.

---

## Ce qui se pose d'abord

| Élément | Emplacement | Remarque |
|---|---|---|
| Barrettes femelles ESP32 | colonnes 2 et 12, rangées 6 à 24 | 19 trous par rangée, prise USB vers le bas |
| Support DIP-20 | colonnes 16 et 19, rangées 15 à 24 | **encoche vers le haut** |
| Condensateur 100 nF | entre (19, 15) et (19, 16) | broches 20 et 19 du support |
| Connecteur J1, 10 broches | colonne 23, rangées 15 à 24 | vers les drivers |
| Connecteur J2, 10 broches | colonne 23, rangées 2 à 11 | vers les capteurs et le servo |
| **Bus 0 V** | rangée 27, colonnes 2 à 29 | fil **nu étamé**, tendu et soudé à chaque extrémité |
| **Bus +5 V** | colonne 30, rangées 2 à 26 | fil **nu étamé** |

⚠️ Présente l'ESP32 à sec sur la plaque avant de souder les barrettes : l'écartement entre ses deux rangées de broches est de 10 trous sur la plupart des modèles, mais 11 sur certains.

---

## 1 · ESP32 → entrées A du 74HCT245 — 8 fils

| # | De | Trou | Vers | Trou |
|---|---|---|---|---|
| 1 | GPIO 26 · X step | (2, 15) | broche 2 — A1 | (16, 16) |
| 2 | GPIO 16 · X dir | (12, 17) | broche 3 — A2 | (16, 17) |
| 3 | GPIO 25 · Y step | (2, 14) | broche 4 — A3 | (16, 18) |
| 4 | GPIO 27 · Y dir | (2, 16) | broche 5 — A4 | (16, 19) |
| 5 | GPIO 17 · Z step | (12, 16) | broche 6 — A5 | (16, 20) |
| 6 | GPIO 14 · Z dir | (2, 17) | broche 7 — A6 | (16, 21) |
| 7 | GPIO 13 · enable | (2, 20) | broche 8 — A7 | (16, 22) |
| 8 | GPIO 13 · enable | (2, 20) | broche 9 — A8 | (16, 23) |

Les fils 7 et 8 partent bien du **même trou**. Deux fils dans un seul trou passent mal : soude le second sur la pastille du premier, au dos.

## 2 · Sorties B du 74HCT245 → J1 — 8 fils

| # | De | Trou | Vers | Trou |
|---|---|---|---|---|
| 9 | broche 18 — B1 | (19, 17) | J1-1 | (23, 15) |
| 10 | broche 17 — B2 | (19, 18) | J1-2 | (23, 16) |
| 11 | broche 16 — B3 | (19, 19) | J1-3 | (23, 17) |
| 12 | broche 15 — B4 | (19, 20) | J1-4 | (23, 18) |
| 13 | broche 14 — B5 | (19, 21) | J1-5 | (23, 19) |
| 14 | broche 13 — B6 | (19, 22) | J1-6 | (23, 20) |
| 15 | broche 12 — B7 | (19, 23) | J1-7 | (23, 21) |
| 16 | broche 11 — B8 | (19, 24) | J1-8 | (23, 22) |

## 3 · ESP32 → J2 — 6 fils

| # | De | Trou | Vers | Trou |
|---|---|---|---|---|
| 17 | GPIO 4 · fin de course X | (12, 18) | J2-1 | (23, 2) |
| 18 | GPIO 21 · fin de course Y | (12, 11) | J2-2 | (23, 3) |
| 19 | GPIO 22 · Hall index Z | (12, 8) | J2-3 | (23, 4) |
| 20 | GPIO 32 · casse-fil | (2, 12) | J2-4 | (23, 5) |
| 21 | GPIO 33 · arrêt d'urgence | (2, 13) | J2-5 | (23, 6) |
| 22 | GPIO 18 · servo | (12, 14) | J2-6 | (23, 7) |

## 4 · Alimentation +5 V — 5 fils

| # | De | Trou | Vers |
|---|---|---|---|
| 23 | broche 5V de l'ESP32 | (2, 24) | bus +5 V, vers (30, 26) |
| 24 | broche 20 — VCC | (19, 15) | bus +5 V, vers (30, 13) |
| 25 | broche 1 — DIR | (16, 15) | bus +5 V, vers (30, 12) |
| 26 | J2-8 | (23, 9) | bus +5 V, vers (30, 9) |
| 27 | J2-9 | (23, 10) | bus +5 V, vers (30, 10) |

## 5 · Masse 0 V — 7 fils

| # | De | Trou | Vers |
|---|---|---|---|
| 28 | GND de l'ESP32 | (2, 19) | bus 0 V, vers (2, 27) |
| 29 | broche 10 — GND | (16, 24) | bus 0 V, vers (16, 27) |
| 30 | broche 19 — OE | (19, 16) | bus 0 V, vers (19, 27) |
| 31 | J1-9 | (23, 23) | bus 0 V, vers (24, 27) |
| 32 | J1-10 | (23, 24) | bus 0 V, vers (25, 27) |
| 33 | J2-7 | (23, 8) | bus 0 V, vers (27, 27) |
| 34 | J2-10 | (23, 11) | bus 0 V, vers (26, 27) |

**34 fils au total.** Compte-les à la fin : c'est le contrôle le plus simple.

---

## Brochage des connecteurs

### J1 — faisceau vers les drivers

| Broche | Signal | Destination |
|---|---|---|
| 1 | B1 | PUL+ du driver X |
| 2 | B2 | DIR+ du driver X |
| 3 | B3 | PUL+ de Y1 **et** Y2 |
| 4 | B4 | DIR+ de Y1 **et** Y2 |
| 5 | B5 | PUL+ du driver Z |
| 6 | B6 | DIR+ du driver Z |
| 7 | B7 | ENA+ de X **et** Z |
| 8 | B8 | ENA+ de Y1 **et** Y2 |
| 9 | 0 V | retours PUL− DIR− ENA− |
| 10 | 0 V | retours PUL− DIR− ENA− |

### J2 — capteurs et servo

| Broche | Signal |
|---|---|
| 1 | GPIO 4 — fin de course X |
| 2 | GPIO 21 — fin de course Y |
| 3 | GPIO 22 — Hall, index Z |
| 4 | GPIO 32 — détecteur de casse-fil |
| 5 | GPIO 33 — arrêt d'urgence |
| 6 | GPIO 18 — signal du servo |
| 7 | 0 V |
| 8 | +5 V |
| 9 | +5 V |
| 10 | 0 V |

---

## Ordre de montage

1. Les **barrettes femelles** de l'ESP32 et le **support DIP-20**. Souder d'abord une broche à chaque extrémité, vérifier que la pièce est bien à plat, puis souder le reste.
2. Les **deux bus** en fil nu étamé, bien tendus.
3. Le **condensateur 100 nF**, au ras du support.
4. Les **connecteurs** J1 et J2.
5. Les **34 liaisons**, une couleur à la fois : les oranges, puis les marron, puis les bleues, puis le +5 V, puis le 0 V. Coche au fur et à mesure.

---

## Vérifications au multimètre, avant d'insérer les composants

Le support et les barrettes sont soudés, mais **ni l'ESP32 ni le 74HCT245 ne sont en place**.

| Vérification | Attendu |
|---|---|
| Entre le bus +5 V et le bus 0 V | **circuit ouvert** |
| Broche 20 du support ↔ bus +5 V | continuité |
| Broche 1 du support ↔ bus +5 V | continuité |
| Broche 19 du support ↔ bus 0 V | continuité |
| Broche 10 du support ↔ bus 0 V | continuité |
| Chaque broche A du support ↔ le GPIO correspondant | continuité |
| Deux broches voisines du support entre elles | **circuit ouvert** |

Ce dernier point est le plus important : un pont de soudure entre deux broches adjacentes est la faute la plus courante, et la plus discrète. Passe-les toutes en revue, deux par deux.

## Ce qui ne passe pas par la plaque

Le 48 V, le 19,5 V et les fils moteur vont de l'alimentation **directement** aux borniers à vis des drivers. Aucune piste de plaque perforée n'est faite pour 4 A, et ces courants n'ont rien à faire près des signaux.

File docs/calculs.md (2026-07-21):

# Calculs et dimensionnement

## Résolution des axes X/Y

Nema 17 (200 pas/tour) en 1/16 de pas, poulie GT2 20 dents :

```
3200 pas/tour ÷ 40 mm/tour = 80 pas/mm     →  résolution 0,0125 mm
```

## Résolution de l'axe Z

Z est exprimé en **degrés d'arbre principal**. Nema 23 en 1/4 de pas, réduction 2:1 :

```
800 pas/tour moteur × 2 = 1600 pas par tour d'arbre
1600 ÷ 360 = 4,4444 pas par degré           →  résolution 0,225°
```

Bien assez : on a seulement besoin de savoir si l'aiguille est haute ou basse.

## Fréquence de pas

C'est ce qui a écarté l'Arduino Uno du projet.

| Axe | Microstepping | Vitesse | Fréquence |
|---|---|---|---|
| Z | 1/16 | 400 pts/min, 2:1 | **42 700 pas/s** ❌ |
| Z | **1/4** | 400 pts/min, 2:1 | **10 700 pas/s** ✅ |
| X/Y | 1/16 | 120 mm/s | **9 600 pas/s** ✅ |

GRBL sur ATmega328P plafonne vers **30 kHz**. FluidNC sur ESP32 tient 100 kHz et plus.

## Dynamique des axes X/Y

Un point moyen fait 3 mm et doit s'exécuter pendant la demi-rotation « aiguille haute », soit ~50 ms à 400 points/min. Avec un profil triangulaire :

```
a = 4s/t²  = 4 × 3 mm / (0,050 s)²  = 4800 mm/s²
v_max = a·t/2 = 120 mm/s
```

Effort correspondant, pour une masse mobile estimée à 400 g (cadre + bras) :

```
F = m·a = 0,4 × 4,8 = 1,92 N
couple sur poulie GT2 20 dents (r = 6,37 mm) = 12,2 mN·m
```

Un Nema 17 de 0,4 N·m offre **plus de 30× de marge**. Le facteur limitant en X/Y n'est donc pas le couple mais la **rigidité** : c'est la flexion du bras porte-cadre qui décale les points, pas un manque de puissance.

## Pourquoi 48 V sur l'axe Z

Un moteur pas-à-pas fait 50 cycles électriques par tour. À chaque demi-cycle, le driver doit inverser le courant dans l'inductance du bobinage, ce qui prend `L × 2I / V` secondes.

Pour le Nema 23 de 3 N·m (L ≈ 3,6 mH, I = 4,2 A) :

| Vitesse moteur | Demi-période | Besoin 24 V | Besoin 48 V |
|---|---|---|---|
| 500 tr/min | 1,20 ms | 1,26 ms ❌ | 0,63 ms ✅ |
| 800 tr/min | 0,75 ms | 1,26 ms ❌ | 0,63 ms ✅ |
| 1000 tr/min | 0,60 ms | 1,26 ms ❌ | 0,63 ms ✅ |

**En 24 V, le moteur décroche dès 500 tr/min**, soit 250 points/min à la machine. Le 48 V n'est pas une optimisation, c'est une condition de fonctionnement.

## Pourquoi garder le rapport 2:1

Contre-intuitivement, réduire le rapport ne sert à rien.

Au-delà de sa vitesse de coude, un pas-à-pas travaille à **puissance constante** : le rapport multiplie le couple par 2, mais oblige le moteur à tourner deux fois plus vite, où il a deux fois moins de couple. Les deux effets s'annulent.

En revanche, le rapport divise l'**inertie ramenée** du volant en fonte par son carré :

| Rapport | Inertie ramenée / inertie rotor |
|---|---|
| 1:1 | 17,8 : 1 ⚠️ décrochage au démarrage |
| 1,5:1 | 7,9 : 1 |
| **2:1** | **4,5 : 1** ✅ |

À 1:1, le moteur voit 18× sa propre inertie et décroche à chaque accélération. Le 2:1 ramène ça à 4,5:1, ce qui est sain.

**Conserver le volant en fonte** : l'énergie de pénétration de l'aiguille vient majoritairement de son inertie, pas du moteur. C'est l'amortisseur de couple d'impact.

## Entraxe imposé par la courroie

Courroie HTD 5M en boucle fermée de 500 mm, poulies 20 et 40 dents :

```
Ø primitif 20 dents = 20 × 5 / π = 31,8 mm
Ø primitif 40 dents = 40 × 5 / π = 63,7 mm

L = 2C + π(D₁+D₂)/2 + (D₂−D₁)²/(4C)
500 = 2C + 150,0 + 1013/(4C)
```

→ **C ≈ 174 mm** entre l'axe moteur et l'axe du volant.

Cette cote n'est **pas réglable** : une boucle fermée ne se raccourcit pas. À vérifier physiquement sur la Singer avant de percer le bâti.

## Force centrifuge sur l'aimant d'index

Aimant néodyme 5 × 2 mm (≈ 0,29 g) à r = 35 mm, à 1000 tr/min :

```
ω = 104,7 rad/s
a = ω²r = 384 m/s² = 39 g
F = 0,29 g × 39 g = 0,11 N
```

Négligeable — la colle suffit. Prévoir tout de même un logement fermé par une couche imprimée par-dessus plutôt qu'un simple collage de surface.

## Limite de précision de l'axe Z

FluidNC stocke les positions en **float 32 bits**, dont la mantisse de 24 bits sature vers 16,7 millions. Au-delà, la résolution de Z se dégrade à plus d'un degré par incrément.

À 360° par point, cela survient vers **46 000 points**. Le post-processeur remet donc Z à zéro par un `G92 Z0` lors des arrêts naturels (saut, coupe, changement de couleur) et signale un dépassement si un motif enchaîne trop de points sans pause.

## Cadence réaliste

| Machine | Points/min |
|---|---|
| Brodeuse commerciale monotête | 800–1200 |
| **Objectif de ce projet** | **400–500** |
| Premiers essais recommandés | 100–200 |

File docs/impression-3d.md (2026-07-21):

# Impression 3D

## Pièces à modéliser

| Pièce | Fonction | Criticité |
|---|---|---|
| Poulie HTD 5M 40 dents | entraînement Z, alésage 20,5 mm | 🔴 haute |
| Bras porte-cadre | liaison chariot ↔ cadre de broderie | 🔴 haute |
| Support capteur Hall | fixation sur le bâti | 🟢 faible |
| Roue de détection casse-fil | avec logement d'aimant | 🟡 moyenne |
| Support moteur Nema 23 | fixation sur la Singer | 🟠 |

## Paramètres

| Réglage | Valeur |
|---|---|
| Matériau | PETG-CF |
| Buse | acier trempé, 0,4 mm |
| Hauteur de couche | 0,20 mm |
| Périmètres | 5–6 |
| Top / bottom | 5 |
| Remplissage | 40 % gyroïde |
| Séchage filament | **obligatoire** — le PETG-CF est très hygroscopique |

Les périmètres font la solidité, pas le remplissage. Mais 10 périmètres à 0,4 mm plus 50 % de gyroïde donne une pièce quasi pleine : 5–6 périmètres et 40 % suffisent largement et divisent le temps d'impression.

## Ce qui compte vraiment : l'orientation

Le point faible du PETG-CF est l'**adhésion inter-couches**. La fibre de carbone rigidifie dans le plan XY mais n'apporte rien en Z.

**Orienter chaque pièce pour que les efforts soient dans le plan des couches, jamais en délaminage.**

Cas concret de la poulie 40 dents : imprimée à plat (axe vertical), ses dents travaillent en cisaillement inter-couches — exactement le mode de rupture à éviter. C'est le principal argument contre l'impression de cette pièce.

## ⚠️ La poulie 40 dents

Deux problèmes se cumulent :

**Le fluage.** Un ajustement serré en PETG-CF se relâche sous charge cyclique. Après quelques heures de fonctionnement, du jeu apparaît sur l'alésage de 20,5 mm, et la synchronisation aiguille/cadre part avec.

**La transmission du couple.** Un simple ajustement serré ne suffit pas. Il faut une liaison mécanique positive :

- moyeu fendu serré par vis M4, ou
- méplat sur l'arbre + vis pointeau, ou
- insert métallique noyé

**Recommandation : acheter une poulie HTD 5M 40 dents en aluminium et la réaléser à 20,5 mm.** Environ 25 €, et ça supprime le risque le plus sérieux de la partie mécanique. À défaut, imprimer, mais prévoir de la remplacer.

## ⚠️ Le bras porte-cadre

L'ennemi est l'effet « plongeoir » : le bras porte le cadre en porte-à-faux, et sa flexion sous accélération décale la position de l'aiguille — donc les points.

Le module d'Young départage sans appel :

| Matériau | Module |
|---|---|
| PETG-CF | ~4 GPa |
| Aluminium | ~70 GPa |

**Facteur 17.** Aucune nervure ne rattrape ça sur une pièce sollicitée en flexion pure.

Trois options, par ordre de préférence :

1. **Plaque d'aluminium de 4 mm découpée** — radicalement plus rigide, souvent moins cher
2. **Bras imprimé + deuxième point d'appui** (patin glissant sous le bras, en appui sur le plateau de la machine) — supprime le porte-à-faux
3. Bras imprimé nervuré seul — le plus simple, le moins rigide

Rappel du calcul : l'effort n'est que de ~2 N. Ce n'est pas la résistance qui pose problème, c'est la **raideur**.

## Aimant d'index

Logement pour aimant néodyme 5 × 2 mm dans la poulie 40 dents, à environ 35 mm du centre.

La force centrifuge est négligeable (0,11 N à 1000 tr/min), la colle suffit. Prévoir tout de même un **logement fermé par une couche imprimée par-dessus** plutôt qu'un collage de surface — une pièce qui se détache à 1000 tr/min à côté d'une aiguille, ce n'est pas le moment de découvrir que la colle avait lâché.

## Fixation du cadre

Le « hack » retenu : une rigole en bout de bras, le cadre percé de deux trous de 4,5 mm, fixé par deux boulons M4 et des écrous papillon.

Deux précautions :

- **Entraxe des boulons ≥ 40 mm.** Avec deux points rapprochés, le cadre peut pivoter autour de leur axe et vibrer.
- **Portée plane large**, pas une rigole ponctuelle.

Percer le cadre en ABS moulé avec un foret à étages, lentement — l'ABS fissure facilement.

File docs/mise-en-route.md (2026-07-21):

# Mise en route et calibration

## 1. Flasher FluidNC

Depuis Chrome ou Edge, ouvrir [installer.fluidnc.com](http://installer.fluidnc.com) et suivre l'assistant. Le CP2102 est reconnu nativement, aucun pilote à installer.

⚠️ Choisir la version pour **ESP32** classique (Xtensa LX6). FluidNC v3 ne prend pas en charge les ESP32-S3 / C3 / C6.

Une fois flashé, téléverser `firmware/fluidnc-config.yaml` via l'interface web, puis :

```
$Config/Filename=fluidnc-config.yaml
$System/Control
```

## 2. Vérifier les signaux avant de brancher les moteurs

**Moteurs débranchés**, drivers alimentés. Dans la console FluidNC :

```gcode
$J=G91 X10 F500
```

Vérifier à l'oscilloscope ou au multimètre que les impulsions arrivent bien en 5 V sur les entrées `PUL+` du driver. Si les LED des drivers ne réagissent pas, le problème vient presque toujours du 74HCT245 (broche `OE` non reliée à la masse, ou `DIR` non reliée au +5 V).

## 3. Sens de rotation

Brancher un moteur à la fois. Si un axe part à l'envers, inverser la ligne `direction_pin` du YAML ou permuter une paire de fils du moteur.

## 4. Indexation de l'axe Z

C'est la première chose à régler, et elle conditionne tout le reste.

1. Faire tourner Z à la main jusqu'au **point mort haut** de l'aiguille
2. Positionner le capteur Hall pour qu'il déclenche exactement à cet instant
3. Vérifier la polarité de l'aimant — le KY-003 utilise un A3144, capteur **unipolaire** qui ne réagit qu'à un seul pôle. Si rien ne se déclenche, retourner l'aimant
4. Lancer `$H` et vérifier que l'aiguille s'immobilise bien en haut

## 5. Origine du cadre

Le post-processeur génère des coordonnées **centrées sur zéro** : le motif s'étend de part et d'autre de l'origine. Il faut donc placer le zéro pièce au centre du cadre.

```gcode
$H                      ; homing
; déplacer manuellement le cadre jusqu'à son centre géométrique
G10 L20 P1 X0 Y0        ; définir ce point comme origine G54
```

## 6. Calibration des pas par mm

Commander un déplacement de 100 mm, mesurer le déplacement réel :

```
steps_per_mm corrigé = 80 × (100 / mesure_réelle)
```

Un écart de plus de 2 % indique généralement une poulie qui n'a pas le nombre de dents annoncé, ou une courroie qui patine.

## 7. Montée en cadence

Ne pas démarrer à 400 points/min. Progresser :

| Étape | Cadence | Objectif |
|---|---|---|
| 1 | 60 pts/min | vérifier la synchronisation aiguille/cadre à l'œil |
| 2 | 150 pts/min | premier motif complet sur chute de tissu |
| 3 | 250 pts/min | vérifier l'absence de points sautés |
| 4 | 400 pts/min | cadence de production |

```bash
python3 postproc/dst2gcode.py motif.dst -o motif.nc --spm 60
```

## 8. Réglage des accélérations

Les valeurs du YAML sont volontairement prudentes. Deux symptômes opposés :

**Points décalés, motif déformé** → l'accélération X/Y est trop élevée, les moteurs perdent des pas, ou le bras porte-cadre fléchit. Réduire `acceleration_mm_per_sec2`, ou rigidifier le bras.

**L'axe Z ralentit visiblement entre les points** → le planificateur décélère à chaque changement de direction en XY, ce qui freine aussi Z. Augmenter `acceleration_mm_per_sec2` sur X et Y, et relever la déviation de jonction :

```
$GCode/JunctionDeviation=0.05
```

C'est le réglage le plus délicat du projet : il faut que Z ne s'arrête **jamais** complètement, sous peine de faire décrocher le volant en fonte au redémarrage.

## 9. Réglages machine indispensables

Aucun G-code ne compensera ces points :

- **Pied à repriser monté** — un pied normal baissé bloque le tissu, relevé il laisse le tissu remonter avec l'aiguille et les points sautent
- **Griffes d'entraînement abaissées** ou couvertes par une plaque
- **Tension du fil supérieur réduite** par rapport à la couture normale
- **Tissu bien tendu** dans le cadre, avec un stabilisateur (entoilage) en dessous

## Dépannage

| Symptôme | Cause probable |
|---|---|
| Points sautés systématiques | pied à repriser absent ou mal réglé, tension trop forte |
| L'aiguille casse | cadre mal fixé, ou bras qui fléchit sous l'accélération |
| Z décroche au démarrage | accélération Z trop élevée, ou alimentation en 24 V au lieu de 48 V |
| Pas manqués aléatoires en X/Y | `pulse_us` trop court pour les optocoupleurs — remonter à 4–6 µs |
| Motif décalé progressivement | perte de pas ; vérifier le courant des drivers et la tension des courroies |
| Broderie dans le vide | fil cassé — d'où l'intérêt du détecteur |

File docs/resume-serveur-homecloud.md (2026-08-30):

# Ce qui a été ajouté au serveur homecloud

Document de contexte à donner à une autre session Claude, en complément du résumé général du serveur. Décrit uniquement ce que le projet brodeuse a installé, et ce qu'il ne faut pas casser.

---

## En une phrase

Une application Flask pilote une machine à coudre Singer transformée en brodeuse CNC, branchée en USB directement sur le serveur. Elle tourne dans son propre conteneur Docker, isolée de Nextcloud et Immich, et se met à jour toute seule depuis GitHub.

---

## Emplacement et ports

| | Valeur |
|---|---|
| Dossier | `~/apps/brodeuse/Singer_CNC_projet_broderie/` |
| Compose | `<dossier>/deploiement/docker-compose.yml` |
| Conteneur | `brodeuse` |
| Image | `deploiement-brodeuse:latest` (construite localement) |
| Port hôte | **8091**, exposé sur toutes les interfaces (accès LAN direct) |
| Réseau Docker | dédié (`deploiement_default`), **pas** `cloud-network` |
| Dépôt distant | `https://github.com/Haldin77/Singer_CNC_projet_broderie` |

L'application n'utilise ni Redis ni Postgres. Aucune interaction avec l'existant.

---

## Accès matériel — le point sensible

Le conteneur pilote deux périphériques USB série :

- **la carte de commande** (ESP32 sous FluidNC, puce CP210x `10c4:ea60`)
- **la pédale** (Arduino Uno, puce CH340 `1a86:7523`)

Trois mécanismes rendent cet accès fiable, et **aucun ne doit être retiré** :

**Règle udev** dans `/etc/udev/rules.d/99-brodeuse.rules` — crée les liens stables `/dev/brodeuse-carte` et `/dev/brodeuse-pedale`. Sans elle, l'ordre de branchement décide qui est `ttyUSB0` : le serveur ferait tourner l'arbre principal en croyant lire la pédale.

**`/dev` monté en entier** dans le compose, plutôt que `devices:`. L'ESP32 se réinitialise régulièrement ; avec `devices:`, le nœud est figé à la création du conteneur et la liaison reste morte jusqu'au redémarrage.

**`device_cgroup_rules`** (`c 188:* rmw` pour ttyUSB, `c 166:* rmw` pour ttyACM) et **`group_add: ["20"]`** (groupe `dialout`) — permettent d'ouvrir les ports sans passer le conteneur en `privileged`.

---

## Redéploiement automatique

GitHub ne peut pas joindre le serveur (aucune redirection de port, tout passe par Tailscale). C'est donc le serveur qui interroge, toutes les deux minutes.

- `deploiement/redeployer.sh` — le script
- `/etc/systemd/system/brodeuse-maj.service` et `.timer`

Le script fait, dans l'ordre : remise à zéro des modifications locales (`git checkout -- .`), `git fetch`, comparaison des révisions, **refus de redémarrer si une broderie est en cours** (il interroge `/api/etat`), puis `git pull` et redémarrage du conteneur. Il ne reconstruit l'image que si `requirements.txt` ou le `Dockerfile` ont changé — le dépôt étant monté depuis l'hôte, un redémarrage suffit pour une simple modification de code.

Diagnostic :

```bash
systemctl list-timers brodeuse-maj
journalctl -u brodeuse-maj -n 30
```

---

## Contraintes à connaître avant de modifier quoi que ce soit

**Un seul processus, jamais de workers.** L'état de la machine, le fil d'envoi du G-code et la boucle de pédale vivent en mémoire dans un objet unique, et un seul propriétaire peut détenir le port série. Lancer l'application derrière Gunicorn avec plusieurs workers la casserait : chacun tenterait d'ouvrir la même carte, et l'interface répondrait différemment selon le worker atteint. Le serveur de développement Flask en `threaded=True` est ici le bon choix, pas un pis-aller.

**Aucune authentification.** Quiconque atteint le port 8091 peut lancer une broderie ou déplacer les axes. Acceptable sur un LAN domestique sans redirection de port ; à ne jamais exposer à internet. Une alternative HTTPS via Tailscale et Caddy est décrite dans `docs/deploiement-serveur.md` (port 8444), utilisable en parallèle.

**Le redémarrage automatique de 3 h peut interrompre une broderie.** `unattended-upgrades` redémarre le serveur si le noyau a été mis à jour. Le conteneur repart (`restart: unless-stopped`), le motif en cours est perdu.

**Machine physique dangereuse.** Une aiguille monte et descend sur ordre HTTP. Elle doit être surveillée quand elle tourne.

---

## Dépendances Python

`flask`, `pyserial`, `pyembroidery`, `numpy`, `opencv-python-headless`, `pillow` — figées dans `deploiement/requirements.txt`. Seule dépendance système : `libglib2.0-0`, pour OpenCV en version headless.

---

## Vérifier que tout va bien

```bash
sudo docker ps --filter name=brodeuse
sudo docker logs brodeuse --since 10m
curl -s localhost:8091/api/etat
ls -l /dev/brodeuse-*
```

Le journal doit afficher `Carte : connectee sur /dev/brodeuse-carte`.

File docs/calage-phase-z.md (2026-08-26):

# Caler la phase de l'axe Z

Le capteur Hall donne un repère angulaire à la machine. Mais ce repère n'est utile que si l'on sait **à quoi il correspond** dans le cycle de l'aiguille.

## Pourquoi c'est critique

Le générateur découpe chaque point en deux phases : le cadre se déplace pendant 120°, l'aiguille descend et remonte pendant les 240° restants. Tout repose sur une hypothèse — **Z = 0 signifie aiguille au point mort haut**.

Si l'aimant est décalé, le cadre bouge au mauvais moment du cycle. L'aiguille prend un effort latéral, fléchit, saute des points, et le fil finit par casser.

C'est un décalage invisible : le motif paraît correct, la machine tourne, et pourtant chaque point est posé de travers.

## Le piège du releveur de fil

Sur une machine à coudre, le **releveur de fil atteint son point haut après l'aiguille**. Les deux ne sont pas en phase.

Placer l'aimant en se repérant sur le releveur — ce qui est tentant, car il est bien visible — introduit donc un décalage de plusieurs dizaines de degrés.

## La mesure

Trois commandes, une seule fois.

```
$HZ
```

L'aiguille s'arrête à la position du capteur.

```
$J=G91 Z10 F1800
```

Répète, par paliers de dix degrés, en regardant la **barre à aiguille**. Réduis à `Z2` en approchant. Arrête-toi quand elle est exactement au plus haut de sa course — le moment où elle change de sens.

```
?
```

La valeur de `Z` dans `MPos` est ton décalage.

## Reporter la valeur

Dans `interface/serveur.py`, en tête :

```python
DECALAGE_PHASE_Z_DEG = 42.0    # ta valeur mesurée
```

Le générateur émet alors un `G92 Z-42` en tête de chaque fichier. La machine sait désormais que `Z = 0` désigne l'aiguille en haut, et non l'aimant devant le capteur.

C'est une **propriété de la machine**, pas du motif : elle s'applique aux fichiers issus de la conversion d'image comme à ceux venant d'Ink/Stitch.

## Vérifier

Après avoir reporté la valeur, régénère un motif et relance. Deux signes que c'est juste :

**Le cadre est immobile** au moment où l'aiguille traverse le tissu. Regarde-le de près, au ralenti, en descendant la cadence à 60 points/min.

**Plus de points sautés en série.** Un décalage de phase en provoque par paquets, toujours aux mêmes endroits du motif — dans les courbes serrées, là où le cadre bouge le plus vite.

## Pourquoi le corriger en logiciel

Déplacer l'aimant demanderait de démonter la poulie, de le recoller, de remonter, puis de recommencer si la valeur n'est pas la bonne — plusieurs essais mécaniques pour un réglage qui se fait ici en une ligne.

Et cette ligne est mesurée, pas devinée.

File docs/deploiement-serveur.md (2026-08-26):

# Faire tourner l'interface sur le serveur homecloud

La machine est branchée en USB directement sur le serveur. L'interface y tourne en permanence, et le navigateur — PC, téléphone — ne fait plus que consulter une page.

C'est le bon sens de l'architecture : **la boucle de pilotage reste locale**. Le fil qui rythme la pédale et celui qui envoie le G-code parlent à la carte par USB, sur la même machine. Le réseau ne transporte que des ordres de haut niveau, et sa latence n'entre plus dans la boucle temps réel.

---

## Ce qui est déjà décidé

| | Valeur |
|---|---|
| Port applicatif | **8091** (libre : 22, 80, 443, 2283, 2284, 6379, 8080 sont pris) |
| Port HTTPS Tailscale | **8444** (à ajuster si 2284 a finalement été pris par Immich) |
| Emplacement | `~/apps/brodeuse/` — hors de `~/compose/`, comme recommandé |
| Réseau Docker | dédié, par défaut. L'app n'a besoin ni de Redis ni de Postgres |

---

## 1 · Déposer le projet sur le serveur

```bash
mkdir -p ~/apps/brodeuse
cd ~/apps/brodeuse
git clone <ton-depot> Singer_CNC_projet_broderie
```

Sans dépôt distant, un `scp -r` du dossier depuis le PC fait l'affaire.

Vérifie la place avant de construire l'image — OpenCV et NumPy pèsent leur poids :

```bash
df -h /
```

---

## 2 · Nommer les deux liaisons série

C'est l'étape qu'on ne peut pas sauter. Sans elle, la carte est `/dev/ttyUSB0` un jour et `/dev/ttyUSB1` le lendemain selon l'ordre de branchement — et le serveur fait tourner l'arbre principal en croyant régler la pédale.

Identifie les deux appareils :

```bash
lsusb
```

Tu dois voir `Silicon Labs CP210x` (la carte) et `QinHeng CH340` (la pédale).

Installe la règle :

```bash
sudo cp ~/apps/brodeuse/Singer_CNC_projet_broderie/deploiement/99-brodeuse.rules \
        /etc/udev/rules.d/
sudo udevadm control --reload-rules && sudo udevadm trigger
```

Contrôle :

```bash
ls -l /dev/brodeuse-*
```

Tu dois obtenir deux liens symboliques stables, `brodeuse-carte` et `brodeuse-pedale`.

> Si tu as plusieurs adaptateurs du même modèle, les identifiants USB ne suffisent plus : ajoute `ATTRS{serial}=="..."` dans la règle, la valeur se lit avec `udevadm info -a -n /dev/ttyUSB0 | grep serial`.

Vérifie aussi le GID du groupe `dialout`, utilisé dans le compose :

```bash
getent group dialout
```

Si ce n'est pas 20, corrige `group_add` dans `docker-compose.yml`.

---

## 3 · Démarrer le conteneur

```bash
cd ~/apps/brodeuse/Singer_CNC_projet_broderie/deploiement
sudo docker compose up -d --build
sudo docker logs -f brodeuse
```

Tu dois lire `Carte : connectee sur /dev/brodeuse-carte` et `Pedale : connectee sur /dev/brodeuse-pedale`.

Test local avant d'aller plus loin :

```bash
curl -s localhost:8091/api/etat
```

---

## 4 · Exposer en HTTPS sur le tailnet

Dans `~/caddy/Caddyfile`, ajoute :

```
homecloud.tail50ff93.ts.net:8444 {
    tls /etc/caddy/cert.crt /etc/caddy/cert.key
    reverse_proxy localhost:8091
}
```

Puis :

```bash
sudo docker restart caddy
sudo ufw allow in on tailscale0 to any port 8444
```

L'interface est alors sur `https://homecloud.tail50ff93.ts.net:8444`, accessible depuis n'importe quel appareil du tailnet.

**Aucune redirection de port sur le routeur.** Une aiguille qui monte et descend sur ordre HTTP n'a rien à faire sur internet ouvert.

---

## Les quatre pièges de ce déploiement

### Un seul processus, jamais de workers

L'état de la machine, le fil d'envoi du G-code et la boucle de pédale vivent **en mémoire, dans un objet unique**. Lancer l'application derrière Gunicorn avec plusieurs workers donnerait à chacun sa propre copie — et chacun tenterait d'ouvrir le même port série. Le premier gagne, les autres échouent, et l'interface répond différemment selon le worker qui reçoit la requête.

Le serveur de développement Flask en `threaded=True` est ici le bon choix, pas un pis-aller : un processus, plusieurs fils, un seul propriétaire de la liaison série.

### Le redémarrage automatique à 3 h

`unattended-upgrades` est réglé pour redémarrer le serveur à 3 h du matin si le noyau a été mis à jour. Une broderie en cours à cette heure-là est perdue — `restart: unless-stopped` relance le conteneur, pas le motif.

Sur un logo dense, une broderie dure trente minutes. Le risque est faible mais réel si tu lances tard. À toi de voir si tu décales cette fenêtre :

```bash
sudo nano /etc/apt/apt.conf.d/50unattended-upgrades   # Unattended-Upgrade::Automatic-Reboot-Time
```

### L'ESP32 qui se réinitialise

C'est pour ça que le compose monte `/dev` en entier au lieu d'utiliser `devices:`. Avec `devices:`, le nœud est figé à la création du conteneur : si la carte disparaît et revient, le conteneur continue de parler à un nœud mort jusqu'à ce qu'on le redémarre.

Si malgré tout la liaison reste muette après un débranchement :

```bash
sudo docker restart brodeuse
```

### La machine devient pilotable depuis le tailnet

N'importe quel appareil connecté à ton tailnet peut lancer une broderie ou activer la pédale. C'est voulu — c'est tout l'intérêt — mais garde-le en tête : la machine doit être **surveillée quand elle tourne**, et le fait de pouvoir la démarrer depuis le canapé ne change rien à ça.

Le détecteur de casse de fil sur GPIO 32, conçu et documenté mais jamais installé, prend d'ailleurs tout son sens dans cette configuration.

---

## Mettre à jour le code

Le dépôt est monté depuis l'hôte, donc :

```bash
cd ~/apps/brodeuse/Singer_CNC_projet_broderie
git pull
sudo docker restart brodeuse
```

Reconstruire l'image (`--build`) n'est nécessaire que si `requirements.txt` change.

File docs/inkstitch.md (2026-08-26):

# Numériser avec Ink/Stitch

Pour un logo soigné, le meilleur chemin n'est pas la conversion d'image de ce projet : c'est **Ink/Stitch**, une extension libre et gratuite d'Inkscape.

C'est un vrai logiciel de numérisation, avec des années de mise au point : point de bourdon, remplissages, sous-couches, compensation d'étirement, ordonnancement — le tout réglable objet par objet, à la main, avec un aperçu fidèle.

## Le partage des rôles

```
Inkscape + Ink/Stitch  →  fichier DST  →  cette interface  →  machine
   numérisation                            pilotage machine
```

**Ink/Stitch décide où vont les points.** Il fait ce travail bien mieux que n'importe quelle conversion automatique d'image.

**Cette interface parle à la machine.** C'est ce qu'aucun logiciel de broderie ne sait faire ici : l'axe Z rotatif en degrés d'arbre, les demi-rotations synchronisées avec le déplacement du cadre, les nœuds d'arrêt, les traversées brodées, les pauses pour lever le pied, l'envoi ligne par ligne par USB.

## En pratique

1. Installe **Inkscape**, puis l'extension **Ink/Stitch** (inkstitch.org).
2. Ouvre ton logo, vectorise-le si besoin (`Chemin → Vectoriser un objet matriciel`).
3. Numérise : `Extensions → Ink/Stitch → Paramètres`. Tu choisis pour chaque objet s'il est en point de bourdon, en remplissage, en trait simple, avec quelle densité.
4. Exporte en **DST** : `Fichier → Enregistrer une copie`, format `Ink/Stitch: DST`.
5. **Dépose le .dst dans cette interface**, comme une image.

Le fichier est reconnu automatiquement. Les réglages de conversion sont ignorés — les points viennent d'Ink/Stitch — mais tout le reste s'applique : nœuds d'arrêt, traversées, pauses, aperçu, statistiques et envoi.

Formats acceptés : **DST, PES, EXP, JEF, VP3, PEC, XXX, HUS, SEW**.

## Deux points à surveiller

**La taille.** Le champ utile est de 165 × 114 mm. L'interface prévient si des points tombent dehors, mais le redimensionnement se fait dans Ink/Stitch, pas ici.

**Les changements de couleur.** Ink/Stitch en génère un par couleur ; chacun devient un arrêt où la machine attend que tu changes de bobine.

## Quand rester sur la conversion d'image

Elle garde son intérêt pour un essai rapide, une silhouette simple, ou quand on ne veut pas ouvrir Inkscape. Le mode automatique mesure le dessin et choisit des réglages corrects.

Mais pour un logo qu'on va broder sur un vêtement et regarder longtemps, Ink/Stitch donnera toujours un meilleur résultat — parce qu'un humain y décide, objet par objet, ce qu'un algorithme ne peut que deviner.

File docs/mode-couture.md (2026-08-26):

# Mode couture

Utiliser la machine comme une machine à coudre ordinaire : seul l'arbre principal tourne, le cadre reste parqué.

## Installation — une seule fois

Téléverse `interface/couture.html` dans le **Flash Filesystem** de l'ESP32, exactement comme tu l'avais fait pour le YAML. Le fichier pèse 12 ko.

Puis, dans le navigateur :

```
http://192.168.1.7/couture.html
```

Pas de PC allumé, pas de Python, pas de serveur. La page est servie par la carte et lui parle directement. Elle marche depuis un téléphone posé à côté de la machine.

> Il existe aussi `interface/serveur.py`, une version hébergée sur PC. Elle fait la même chose mais ajoute un saut réseau. Elle ne sert plus qu'à préparer l'interface broderie, qui aura besoin d'un vrai ordinateur pour traiter les images.

## Utilisation

1. **Homing + parcage du cadre.** Obligatoire au premier lancement. La machine indexe l'aiguille au point mort haut et range le chariot hors du plateau.
2. **Régler la cadence** au curseur. 20 points/min pour un réglage à l'œil, 100 à 150 pour coudre normalement.
3. **Maintenir la pédale** — bouton à l'écran, barre d'espace, ou le doigt sur tablette. L'arbre tourne tant que c'est maintenu.
4. **Relâcher** pour arrêter. La décélération est progressive, le volant en fonte n'aime pas les arrêts secs.
5. **Aiguille en haut** termine le tour en cours pour dégager l'aiguille du tissu.

Le compteur d'angle indique où en est l'arbre dans le tour : **0° = point mort haut**, 180° = aiguille au plus bas.

## Comment l'arrêt est sécurisé

C'est le point de conception le plus important, et il vient d'un vrai problème : **si le WiFi coupe pendant que tu couds, un ordre d'arrêt n'arrivera jamais.** Or on a constaté des coupures de plusieurs secondes sur cette machine.

La page n'envoie donc pas un long mouvement qu'il faudrait ensuite annuler. Elle envoie des **salves de deux points**, renouvelées tant que la pédale est maintenue.

Conséquence : dès que les salves cessent d'arriver — pédale relâchée, WiFi coupé, navigateur fermé, téléphone en veille — la machine termine sa salve et s'arrête. Elle n'attend aucun ordre. Le pire cas est deux points, moins d'une seconde à cadence normale.

L'annulation de jog (`0x85`) est envoyée en plus au relâchement. Quand la liaison tient, l'arrêt est immédiat ; quand elle ne tient pas, le mécanisme de salves prend le relais.

## Points d'attention

**La position machine de Z grandit indéfiniment.** Après plusieurs heures de couture, refais un `$H` pour la remettre à zéro. Rien ne casse sans ça, mais l'affichage perd en précision.

**Si la fenêtre perd le focus** pendant que la pédale est enfoncée, l'arrêt est déclenché d'office. Sans ça, un `Alt-Tab` malheureux laisserait la machine tourner.

**Le mode couture ne coupe pas les moteurs X et Y.** Ils restent alimentés et tiennent le chariot en position — `idle_ms: 255` dans le YAML. C'est voulu : un chariot libre dériverait.

**« Un seul point »** est le bouton le plus utile pour les réglages : il fait exactement un tour d'arbre et rend la main aiguille haute.

## Pédale physique — abandonnée pour l'instant

Trois pistes examinées, aucune retenue :

**Interrupteur câblé sur la carte.** Une macro FluidNC se déclenche sur l'activation du contact, jamais sur son relâchement. Un contact ne saurait donc que démarrer. Le bloc de configuration est présent, commenté, en bas de `fluidnc-config.yaml` (GPIO 19).

**Pédale USB.** Elle donne l'appui et le relâchement, mais impose de garder un PC allumé dans la boucle.

**Pédale d'origine Singer**, progressive. Il faudrait lire une entrée analogique pour en faire une vitesse : FluidNC ne sait pas le faire, il faudrait un second microcontrôleur ou du firmware sur mesure.

## Réglages dans `couture.html`

Ils sont regroupés en haut du bloc `<script>` :

| Constante | Rôle |
|---|---|
| `PARK_X`, `PARK_Y` | position de parcage du cadre, en coordonnées machine |
| `POINTS_SALVE` | longueur d'une salve — c'est aussi la distance d'arrêt en cas de coupure |
| `DEG` | degrés par point, ne pas toucher |

`PARK_Y` est à 5 mm, c'est-à-dire tout au fond. À ajuster une fois que tu auras vu ce qui gêne réellement l'accès au plateau.

Augmenter `POINTS_SALVE` rend le mouvement plus fluide sur un réseau lent, mais allonge d'autant l'arrêt en cas de coupure. Deux est un bon compromis.

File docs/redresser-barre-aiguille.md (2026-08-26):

# Redresser la barre à aiguille — Singer 15K88

Protocole à froid, avec des moyens simples. La pièce est introuvable à prix raisonnable en Europe : l'objectif est de récupérer celle qu'on a, sans l'abîmer davantage.

**La règle qui gouverne tout : on presse, on ne frappe jamais.** La barre coulisse dans deux bagues bronze avec un jeu de quelques centièmes. Un coup de marteau laisse un bourrelet de matière qui bloque dans la bague — un défaut bien pire qu'une flèche de deux dixièmes, et celui-là est irrattrapable.

---

## 0 · Vérifier que c'est bien elle

Avant de démonter, écarte les deux autres coupables possibles :

- **l'aiguille elle-même** — monte-en une neuve, c'est gratuit
- **la pince d'aiguille** — si elle est faussée, l'aiguille part de travers alors que la barre est droite

Test : aiguille neuve montée, tourne le volant à la main lentement et regarde l'aiguille entrer dans le trou de la plaque. Si elle est centrée en haut de course et décalée en bas — ou l'inverse — le défaut est dans la barre ou la pince. Si elle est décalée pareil partout, c'est un problème de position, pas de rectitude.

---

## 1 · Déposer la barre

1. Retire la plaque frontale (une ou deux vis).
2. Retire l'aiguille et la pince.
3. Desserre la **vis du goujon de bielle** (le goujon qui relie la barre à la bielle d'entraînement — réf. 125276 sur ce modèle, vis 1341).
4. Fais glisser la barre vers le bas, hors des deux bagues.

Note au feutre, sur le haut de la barre, l'orientation d'origine — le méplat regarde dans une direction précise, et tu voudras la remonter pareil.

Nettoie-la entièrement : dégraissant, puis chiffon. Toute crasse fausserait la mesure qui suit.

---

## 2 · Mesurer la flèche

Il faut savoir **de combien** elle est tordue et **où**, sinon on corrige à l'aveugle.

### Méthode A — le comparateur (la bonne)

Un comparateur à cadran et deux vés coûtent une vingtaine d'euros et te resserviront sur toute la machine.

- barre posée sur les deux vés, écartés au maximum
- palpeur au milieu, entre les deux
- tourne la barre d'un tour complet, lentement
- l'écart entre la valeur mini et la valeur maxi est la **flèche totale** (TIR)

Refais la mesure en déplaçant le palpeur le long de la barre pour trouver **où** la flèche est maximale : c'est là qu'il faudra presser.

### Méthode B — le roulage sur verre (sans rien acheter)

Une plaque de verre épais, un plan de travail en granit, ou la table d'une scie sur table — quelque chose de vraiment plan.

- pose la barre dessus et fais-la rouler doucement
- une barre droite roule sans à-coup ; une barre tordue **bascule** en passant sur son point haut
- mets une lampe derrière : tu verras la lumière passer sous la barre, et l'endroit où le jour est le plus grand est le sommet de la courbure

Glisse une jauge d'épaisseur sous le jour maximal : tu as la flèche, au centième près.

### Ce que valent les chiffres

| Flèche mesurée | Verdict |
|---|---|
| moins de 0,03 mm | droite, ne touche à rien |
| 0,03 à 0,30 mm | redressable proprement |
| 0,3 à 1 mm | redressable, mais en plusieurs passes et vérifie les bagues |
| plus de 1 mm | l'acier a probablement dépassé sa limite élastique par endroits, et les bagues ont sans doute souffert |

---

## 3 · Marquer le sommet

Barre sur le verre, jour maximal repéré : le sommet de la courbure pointe alors **vers le haut**. Trace un trait de feutre dessus, et une flèche.

C'est le seul point où tu presseras. Presser à côté déplace la courbure au lieu de la supprimer.

---

## 4 · Presser

### Le montage

Il te faut **deux appuis espacés** et **une pression au milieu**, sommet vers le haut.

Au choix, du meilleur au plus rustique :

- **Étau d'établi** : deux barreaux d'acier ronds posés dans les mors comme appuis, la barre à aiguille dessus, et on serre lentement contre un bloc de laiton ou de bois dur.
- **Serre-joint** : deux cales de bois avec une gorge en V, la barre dessus, on serre au milieu à travers une cale de bois dur.
- **Presse à main** de n'importe quel type, même principe.

**Rien de dur en contact direct avec la barre.** Laiton, aluminium, bois dur, cuir — jamais l'acier de l'étau nu.

Écarte les appuis au maximum : plus ils sont loin, plus la correction est douce et progressive.

### Le geste

L'acier a un **retour élastique** : il faut le déformer *au-delà* du droit pour qu'il revienne droit.

1. Serre progressivement jusqu'à sentir la barre céder.
2. Vise un dépassement d'environ **une fois et demie la flèche mesurée** — pour 0,20 mm de flèche, enfonce d'environ 0,30 mm.
3. Relâche complètement.
4. **Remesure.**

Tu seras presque certainement encore loin du compte au premier essai — c'est normal, le retour élastique est difficile à anticiper. Note ce que tu as enfoncé et ce que tu as gagné : dès la deuxième passe tu connaîtras le rapport et tu iras droit au but.

### Les interdits

**Ne chauffe jamais.** La barre est cémentée en surface. Un coup de chalumeau détruit la trempe et tu obtiens une barre molle qui se retordra au premier accroc.

**Ne presse pas sur le trou de pince ni sur le méplat.** Ces zones sont des concentrateurs de contrainte : c'est là que l'acier se fend. Si le sommet de la courbure tombe pile dessus, décale tes appuis pour presser 10 mm à côté et accepte une correction moins directe.

**Va par petits pas.** Trois passes de 0,1 mm valent mieux qu'une de 0,3 mm qui dépasse et qu'il faut reprendre dans l'autre sens — chaque aller-retour fatigue le métal.

---

## 5 · Finir la surface

Une barre redressée porte souvent des marques de contact aux points d'appui.

- **toile émeri fine (600 puis 1000)**, avec de l'huile, en tournant autour de la barre — jamais dans le sens de la longueur
- objectif : **enlever les points hauts uniquement**, pas réduire le diamètre
- contrôle au pied à coulisse en plusieurs endroits : le diamètre doit rester constant

Termine à la laine d'acier 0000 huilée pour un poli glissant.

---

## 6 · Contrôler les bagues

Si la barre a été tordue en service, elle a frotté dur dans ses bagues.

Bagues nettoyées, remonte la barre **à sec** et fais-la coulisser à la main sur toute la course, en la tournant. Tu dois sentir :

- aucun point dur
- aucun jeu de bascule

Un point dur signifie une bague marquée ou ovalisée. Une bague bronze se réalèse à la main avec un alésoir, ou se remplace — c'est une pièce bien plus facile à trouver que la barre.

---

## 7 · Remontage et vérification finale

1. Huile la barre et les bagues.
2. Remonte-la à l'orientation notée à l'étape 1.
3. Goujon de bielle en place, vis serrée.
4. **Règle la hauteur de barre** : aiguille au point mort bas, le chas doit se trouver juste sous le bec du crochet au moment où celui-ci passe. C'est ce réglage qui décide si la boucle est attrapée.
5. Aiguille neuve, tourne le volant à la main sur plusieurs tours complets : l'aiguille doit entrer au centre du trou de plaque, en haut comme en bas de course.

---

## Plan B — faire fabriquer une barre neuve

Si la barre casse ou refuse de se redresser, ce n'est pas une pièce compliquée : un barreau cylindrique rectifié, un trou traversant pour la pince, un méplat pour le goujon, un trou de guide-fil.

De l'**acier argent** (*silver steel* / drill rod) se trouve en barre rectifiée au diamètre exact, tolérance h6, chez n'importe quel fournisseur de mécanique générale, pour quelques euros le mètre. Un tourneur reprend les percages en une demi-heure sur le modèle de l'ancienne.

Vu le prix des originales au Royaume-Uni — et l'incertitude sur leur rectitude — c'est une option sérieuse, pas un pis-aller.

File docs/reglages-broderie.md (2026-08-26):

# Réglages de broderie — quel défaut vient de quoi

Table de diagnostic. Chaque défaut visible renvoie à sa cause la plus probable, et aux suivantes par ordre de fréquence.

Le principe qui fait gagner du temps : **ne change qu'une chose à la fois**, et rebrode le même motif de test entre deux changements.

---

## 1 · Le fil forme des boucles lâches en surface

Le fil du dessus n'est pas tiré dans le tissu, il repose dessus.

| Cause | Vérification | Correction |
|---|---|---|
| **Fil du haut non engagé dans les disques de tension** | enfile toujours **pied relevé** | ré-enfile entièrement, pied relevé, puis abaisse |
| Barre de pied restée levée pendant la broderie | le levier doit être **baissé** | l'abaisser |
| Tension du haut trop faible | on l'a souvent trop détendue en cherchant à éviter la casse | remonte d'un cran, rebrode |
| Fil qui saute d'un guide | suis le trajet du fil du cône à l'aiguille | remets-le dans tous les guides |

C'est la première chose à corriger : tant que le fil n'est pas tenu, aucun autre réglage ne se juge.

---

## 2 · Des zones entières ne sont pas brodées

L'aiguille est passée, mais aucun point ne s'est formé. C'est un **point sauté**, pas un défaut de fichier.

| Cause | Vérification | Correction |
|---|---|---|
| **Crochet et aiguille mal synchronisés** | tourne le volant à la main : la pointe doit passer juste au-dessus du chas, à un cheveu de l'aiguille | calage du crochet — voir plus bas |
| Aiguille pas centrée dans le trou de plaque | regarde-la descendre au ralenti | barre à aiguille ou pince-aiguille |
| Aiguille émoussée ou tordue | change-la, ça coûte un euro | aiguille neuve 130/705 H-E, 75/11 |
| Tissu qui remonte avec l'aiguille | le tissu doit rester plaqué sur la plaque | entoilage plus ferme, cadre plus serré, pied à ressort |
| Cadence trop élevée | redescends à 100 points/min | si ça disparaît, c'est mécanique et ça s'aggrave en vitesse |

Repère utile : si un tour de volant à la main ne remonte pas le fil de canette **à tous les coups**, la synchronisation est en cause, et elle le restera en automatique.

---

## 3 · Le motif est déformé, décalé, ou ne se referme pas

La géométrie n'est pas respectée.

| Cause | Vérification | Correction |
|---|---|---|
| **Support du cadre pas assez rigide** | pousse le cadre du doigt : il ne doit pas fléchir | rigidifier le montage |
| Tissu qui glisse dans le cadre | trace un repère au feutre sur le tissu au bord du cadre | resserrer, ou entoilage plus rugueux |
| Pas perdus en X ou Y | refais `$H` après la broderie : le cadre doit revenir au même endroit | baisser la cadence, ou l'accélération dans le YAML |
| Courroie détendue | pince la courroie : elle doit sonner tendue | retendre |

Le test des pas perdus est décisif et gratuit : **un homing après broderie**. S'il revient juste, la mécanique de mouvement est hors de cause.

---

## 4 · Nid de fil sous le tissu

Un amas de fil emmêlé à l'envers.

**Cause quasi unique : la barre de pied n'était pas abaissée.** C'est elle qui ferme les disques de tension. Le fil du haut descend alors sans aucune retenue et s'accumule sous le tissu.

Vérifie aussi que le fil de canette a bien été remonté avant de démarrer, et que les deux fils étaient tenus vers l'arrière pendant les premiers points.

---

## 5 · Le tissu fronce autour du motif

| Cause | Correction |
|---|---|
| Remplissage trop dense | augmente l'**écartement** : 0,45 → 0,6 ou 0,8 mm |
| Entoilage absent ou trop souple | entoilage à déchirer, ou à découper pour les gros aplats |
| Tension du haut trop forte | détends d'un cran |
| Tissu pas assez tendu | resserre le cadre |

---

## 6 · L'aiguille casse

| Cause | Correction |
|---|---|
| Le cadre bouge pendant que l'aiguille est dans le tissu | déjà corrigé dans le générateur : 120° pour le déplacement, 240° pour la piqûre |
| Le fil est ancré ailleurs et tire | déjà corrigé : la machine se place **d'abord**, on prépare le fil ensuite |
| Aiguille trop fine pour le tissu | passe en 80/12 |
| Aiguille pas enfoncée à fond | remonte-la en butée avant de serrer |

---

## Les réglages du générateur, et leur effet

| Réglage | Trop bas | Trop haut |
|---|---|---|
| **Longueur de point** (2,5 mm) | l'aiguille reperfore au même endroit, le tissu se déchire | points lâches qui s'accrochent, contour anguleux |
| **Écartement du remplissage** (0,45 mm) | fil qui s'accumule, tissu qui fronce, aiguilles cassées | le tissu se voit entre les lignes |
| **Cadence** (250 pts/min) | broderie interminable | pas perdus, points sautés, déformation |
| **Distance de liaison** (5 mm) | beaucoup de sauts et de pauses | liaisons visibles hors matière |
| **Traversée brodée** (30 mm) | des pauses avec le levier | beaucoup de fils à couper |
| **Contour en triple passage** | trait trop fin, à peine visible | trait épais, motif alourdi |

---

## Cas particulier : le tissu hydrosoluble seul

Broder sur du **hydrosoluble sans tissu dessous**, c'est faire de la dentelle libre. C'est un exercice à part, et beaucoup plus exigeant :

- Le film n'a **aucune tenue** : il s'étire sous l'aiguille et la géométrie part de travers.
- Une fois le film dissous, **seul le fil reste**. Un remplissage en lignes parallèles ne tient pas tout seul : il faut des points qui s'entrecroisent, sinon l'ouvrage se défait.
- Il faut une densité bien plus forte, et souvent deux couches de film superposées.

**Pour juger tes réglages, mets du vrai tissu dans le cadre** — une chute de coton un peu épais avec un entoilage à déchirer dessous. Le film hydrosoluble se réserve à deux usages : en **surcouche** sur un tissu pelucheux pour empêcher les points de s'enfoncer, ou pour de la vraie dentelle libre, avec un motif conçu pour ça.

---

## Le calage du crochet

À ne faire qu'après avoir vérifié : aiguille neuve, enfoncée à fond, dans le bon sens, et pointe du crochet intacte.

1. Amène l'aiguille à son point le plus bas.
2. Fais-la remonter d'environ **2,4 mm**.
3. À cet instant, la pointe du crochet doit être **sur l'axe de l'aiguille**, à environ **1,6 mm au-dessus du chas**.
4. Latéralement, elle doit frôler le creux de l'aiguille — quelques centièmes, sans la toucher.

**La hauteur de barre à aiguille se règle avant le calage du crochet, jamais après.** Trace un repère au feutre avant de desserrer quoi que ce soit.

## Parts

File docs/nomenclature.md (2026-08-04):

# Nomenclature et état des commandes

Dernière mise à jour : 20 juillet 2026

## Axe Z — entraînement de l'aiguille

| Pièce | Spécification | État | Prix |
|---|---|---|---|
| Moteur pas-à-pas | Nema 23, **3 N·m**, arbre 8 mm | ✅ reçu | 26,79 € |
| Driver | Cloudray DM542, 20–50 V, 1,0–4,2 A | ✅ reçu | 10,79 € |
| Poulie moteur | HTD 5M, 20 dents, alésage 8 mm, courroie 15 mm | 🚚 en route | 11,21 € |
| Courroie | HTD 5M, boucle fermée 500 mm, largeur 15 mm | 🚚 en route | 11,06 € |
| Poulie machine | HTD 5M **40 dents**, alésage 20,5 mm | ❌ à imprimer | — |
| Capteur d'index | Module Hall KY-003 | 🚚 en route | 5,31 € |
| Aimant | Néodyme 5 × 2 mm | ✅ en stock | — |

**Rapport de réduction : 2:1** (20 → 40 dents). Le moteur tourne deux fois plus vite que l'arbre principal.

⚠️ La courroie est une **boucle fermée de 500 mm**, ce qui impose un entraxe d'environ **174 mm** entre l'axe moteur et l'axe du volant. Cette cote n'est pas réglable.

## Axes X/Y — déplacement du cadre

| Pièce | Spécification | État | Prix |
|---|---|---|---|
| Moteurs | 3 × Nema 17 (42×42), arbre 5 mm, 1,5–1,8 A, 1,8° | ✅ reçu (Leboncoin) | occasion |
| Drivers | 3 × Cloudray DM320S, **12–38 V** (relevé sur étiquette) | ✅ reçu (Leboncoin) | occasion |

Montage Y à **deux moteurs** (un par côté du portique), drivers câblés en parallèle. X = 1 moteur, Y = 2 moteurs → 3 Nema 17, 3 DM320S.
| Poulies | 3 × GT2, 20 dents, alésage 5 mm | 🚚 en route | 7,02 € |
| Courroie | GT2 ouverte, 5 m, largeur 6 mm, caoutchouc | 🚚 en route | 7,15 € |
| Clips de fixation | 4 × clips GT2 aluminium | 🚚 en route | 6,48 € |
| Profilés | 3 × alu 2020V, 500 mm | 🚚 en route | 24,57 € |
| Chariots | 3 × kits roues V + platines 2020 | 🚚 en route | 23,20 € |
| Visserie | 120 pcs, écrous marteau M3/M4/M5 | 🚚 en route | 9,27 € |
| Fins de course | 5 × interrupteurs Arduino | 🚚 en route | 6,77 € |

⚠️ Trois profilés de 500 mm, c'est court pour un portique desservant un cadre 130 × 180. Vérifier les courses avant de percer.

## Contrôleur

| Pièce | Spécification | État | Prix |
|---|---|---|---|
| Microcontrôleur | 2 × ESP32-WROOM-32, 38 broches, CP2102, Type-C | 🚚 en route | 17,95 € |
| Carte d'extension | 2 × borniers à vis 38 broches | 🚚 en route | (incl.) |
| Adaptation de niveau | SN74HCT245N, DIP-20 | ✅ commandé (Addison) | ~2 $ |
| Support | DIP-20 + plaque à pastilles | ✅ commandé (Addison) | — |

## Machine

| Pièce | Spécification | État | Prix |
|---|---|---|---|
| Pied à repriser | Brother/Janome/Singer 4021-L | 🚚 en route | 5,41 € |
| Cadre de broderie | Type Brother SA444, 130 × 180 mm | ✅ reçu (Amazon) | — |
| Câble | Silicone 2 conducteurs, 18 AWG, 5 m | ✅ reçu | 3,99 € |

## Alimentations

Deux alimentations séparées, une par groupe de drivers.

| Alim | Pour | État | Prix |
|---|---|---|---|
| **Mean Well LRS-100-48** — 48 V / 2,1 A | DM542 → Nema 23 (Z) | ✅ commandé (Reichelt) | ~25 € |
| **Bloc HP 19,5 V / 7,69 A** — 150 W | 3 × DM320S → Nema 17 (X, Y1, Y2) | ✅ récupération | 0 € |

### Pourquoi ce découpage

**48 V sur l'axe Z.** À chaque demi-cycle électrique, le driver doit inverser 4,2 A dans l'inductance du bobinage (3,8 mH). Plus la tension est haute, plus vite il y parvient :

| Tension | Décrochage moteur | Cadence machine (2:1) |
|---|---|---|
| 19,5 V | ~350 tr/min | ~175 pts/min |
| 24 V | ~500 tr/min | ~250 pts/min |
| **48 V** | **~900 tr/min** | **~450 pts/min** |

Besoin réel : 32 W de pertes cuivre + ~15 W mécanique, rendement driver 87 % → **~54 W**. Le LRS-100-48 donne 46 % de marge.

**19,5 V sur les axes X/Y.** Les DM320S acceptent 12–38 V, le bloc HP est donc dans la plage avec de la marge des deux côtés. Et cette tension ne bride pas la vitesse : à 120 mm/s (180 tr/min), il faut 0,52 ms pour inverser le courant alors que la demi-période en offre 3,33 — **un facteur 6 de marge**.

⚠️ **Ne jamais mettre 48 V sur les DM320S** (max 38 V). Et éviter le 36 V : avec seulement 2 V de marge, un pic de BEMF suffit à les détruire. Règle d'usage : ne pas dépasser 80 % de la tension max d'un driver.

⚠️ **Condensateur 1000 µF / 35 V** en parallèle sur la sortie du bloc HP, au plus près des drivers : les alims de PC portable supportent mal l'énergie renvoyée par les moteurs en décélération (BEMF). Respecter la polarité.

## ❌ Reste à acquérir

| Pièce | Spécification | Criticité |
|---|---|---|
| Détecteur de casse-fil | Roue libre + capteur Hall ou fourche optique | 🟠 fortement conseillé |
| **Servo de tension** | SG90 ou MG90S, sur la tige de débrayage des disques | 🟠 gère les sauts longs sans casser le fil |
| Arrêt d'urgence | Bouton coup-de-poing câblé sur l'ENABLE | 🟠 sécurité |
| Plaques de renvoi | Plat alu 50 × 5 mm, 6 pièces — voir `hardware/cad/` | 🟠 mécanique |
| Condensateur | 1000 µF / 35 V (protection BEMF) | 🟡 |
| Filament | PETG-CF + buse acier trempé 0,4 mm | 🟡 |

## Budget

| Poste | Montant |
|---|---|
| Commandes AliExpress | ~185 € |
| Occasion Leboncoin (3 Nema 17 + 3 DM320S) | — |
| Alimentation 48 V (Reichelt) | ~25 € |
| Alimentation 19,5 V (récupération) | 0 € |
| **Restant estimé (servo, plat alu, divers)** | **~30 €** |

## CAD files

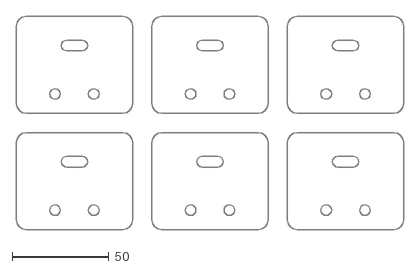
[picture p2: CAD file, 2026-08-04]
hardware/cad/plaque_renvoi_x6.dxf
200.0 x 110.0

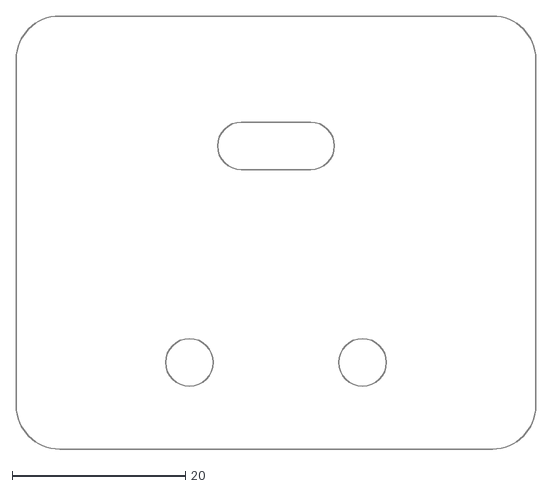
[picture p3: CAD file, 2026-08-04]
hardware/cad/plaque_renvoi.dxf
60.0 x 50.0

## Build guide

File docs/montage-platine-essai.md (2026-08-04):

# Montage sur platine d'essai — sans aucune soudure

Voir le [plan](plan-platine-essai.svg).

L'idée : valider toute la chaîne — ESP32, adaptation de niveau, drivers, moteurs, capteurs — **avant** de souder quoi que ce soit. Le jour où tu passeras à la plaque perforée, tu sauras que le schéma est bon et tu n'auras plus qu'un problème à la fois.

> ⚠️ Ce montage est **provisoire**. Une platine d'essai tient par simple friction : sur une machine qui tape 400 points par minute, les contacts finissent par se relâcher. C'est un banc d'essai, pas la version définitive.

---

## Matériel

| Élément | Remarque |
|---|---|
| 1 demi-platine d'essai (400 points) | une pleine (830) convient aussi |
| 1 lot de cavaliers **femelle-mâle** | ESP32 → platine |
| 1 lot de cavaliers **mâle-mâle** courts | liaisons internes à la platine |
| 1 lot de cavaliers **femelle-femelle** | capteurs → ESP32 |
| 1 condensateur céramique **100 nF** | découplage du 74HCT245 |

L'ESP32 **ne se met pas sur la platine**. Sa largeur couvre presque toutes les rangées utiles, et il faudrait deux platines accolées. Il reste à côté, et on vient chercher ses broches avec des cavaliers femelle-mâle. C'est plus simple et il reste accessible.

---

## Comprendre la platine en trente secondes

Si tu n'en as jamais utilisé, deux règles suffisent :

**Les cinq trous d'une même colonne sont reliés entre eux.** Les rangées `a b c d e` forment un groupe, `f g h i j` en forment un autre. Mettre un fil en `a11` et un autre en `c11`, c'est les relier.

**Le canal central sépare les deux groupes.** C'est ce qui permet aux circuits intégrés de s'enficher à cheval : chaque broche tombe dans une colonne différente, sans court-circuit avec celle d'en face.

**Les longues bandes du haut et du bas** (marquées `+` et `−`) courent sur toute la longueur. Ce sont les rails d'alimentation.

---

## Étape par étape

### 1 · Le circuit intégré

Enfiche le 74HCT245 **à cheval sur le canal central**, encoche vers la gauche, broche 1 en colonne 10.

Ses broches tombent alors ainsi :

| | rangée e (au-dessus du canal) | rangée f (en dessous) |
|---|---|---|
| colonne 10 | broche 1 — DIR | broche 20 — VCC |
| colonne 11 | broche 2 — A1 | broche 19 — OE |
| colonne 12 | broche 3 — A2 | broche 18 — B1 |
| colonne 13 | broche 4 — A3 | broche 17 — B2 |
| colonne 14 | broche 5 — A4 | broche 16 — B3 |
| colonne 15 | broche 6 — A5 | broche 15 — B4 |
| colonne 16 | broche 7 — A6 | broche 14 — B5 |
| colonne 17 | broche 8 — A7 | broche 13 — B6 |
| colonne 18 | broche 9 — A8 | broche 12 — B7 |
| colonne 19 | broche 10 — GND | broche 11 — B8 |

Les pattes d'un DIP neuf sont trop écartées : pose-les à plat sur la table et redresse-les doucement, les deux rangées d'un coup, avant d'enficher. Puis appuie bien à fond, uniformément.

### 2 · L'alimentation du circuit

Quatre cavaliers mâle-mâle, tous verticaux :

| De | Vers | Rôle |
|---|---|---|
| `a10` | rail `+` du haut | broche 1 (DIR) au 5 V |
| `a19` | rail `−` du haut | broche 10 (GND) à la masse |
| `g10` | rail `+` du bas | broche 20 (VCC) au 5 V |
| `g11` | rail `−` du bas | broche 19 (OE) à la masse |

Puis **ponte les rails du haut et du bas** : un cavalier de `+` à `+`, un autre de `−` à `−`. Sans ces deux ponts, la moitié de ton alimentation ne va nulle part — c'est l'erreur classique du débutant sur platine.

### 3 · Le condensateur

Une patte en `i10`, l'autre en `i11`. Il se retrouve ainsi entre les broches 20 et 19, c'est-à-dire entre l'alimentation et la masse de la puce, au plus près. Sa polarité n'a pas d'importance : c'est un céramique.

### 4 · L'alimentation depuis l'ESP32

Deux cavaliers femelle-mâle :

- broche **5V** de l'ESP32 → rail `+`
- broche **GND** de l'ESP32 → rail `−`

### 5 · Les huit signaux

Cavaliers femelle-mâle, côté femelle sur la broche de l'ESP32 :

| GPIO | Vers | Signal |
|---|---|---|
| 26 | `a11` | X step |
| 16 | `a12` | X dir |
| 25 | `a13` | Y step |
| 27 | `a14` | Y dir |
| 17 | `a15` | Z step |
| 14 | `a16` | Z dir |
| 13 | `a17` | enable |
| 13 | `a18` | enable |

Les deux derniers partent de la **même broche** GPIO 13. Sur platine c'est facile : deux cavaliers femelle sur la même broche ne tiennent pas, alors relie plutôt `a17` et `a18` entre eux par un petit cavalier, et n'amène qu'un seul fil depuis GPIO 13.

### 6 · Vers les drivers

Depuis la rangée `j`, huit fils vers les borniers à vis :

| Trou | Vers |
|---|---|
| `j12` | PUL+ du driver X |
| `j13` | DIR+ du driver X |
| `j14` | PUL+ de Y1 **et** Y2 |
| `j15` | DIR+ de Y1 **et** Y2 |
| `j16` | PUL+ du driver Z |
| `j17` | DIR+ du driver Z |
| `j18` | ENA+ de X **et** Z |
| `j19` | ENA+ de Y1 **et** Y2 |

Les `PUL−`, `DIR−` et `ENA−` de tous les drivers vont au rail `−`.

### 7 · Les capteurs, le bouton et le servo

Ils ne passent pas par la platine. Leur fil de signal se branche **directement sur la broche de l'ESP32**, en cavalier femelle-femelle. Leur masse et leur 5 V vont sur les rails.

| Élément | Broche ESP32 |
|---|---|
| Fin de course X | GPIO 4 |
| Fin de course Y | GPIO 21 |
| Hall, index Z | GPIO 22 |
| Détecteur de casse-fil | GPIO 32 |
| Arrêt d'urgence | GPIO 33 |
| Signal du servo | GPIO 18 |

---

## Avant de mettre sous tension

| Vérification | Attendu |
|---|---|
| Entre le rail `+` et le rail `−`, au multimètre | **circuit ouvert** |
| L'encoche du 74HCT245 | vers la gauche |
| Les deux ponts entre rails du haut et du bas | présents |
| Aucune patte du circuit tordue sous le boîtier | à vérifier à l'œil |

Ce dernier point est le piège le plus fréquent : une patte qui s'est repliée sous la puce au lieu d'entrer dans son trou. Vue de dessus, tout paraît normal.

## Le test

```
$X
$J=G91 X10 F500
```

Multimètre sur `j12` : tu dois voir la tension varier pendant le mouvement, 0 V au repos.

Si rien ne bouge nulle part, reprends l'étape 2. Les trois broches d'alimentation du 245 — 1, 19 et 20 — sont la cause de neuf pannes sur dix.

---

## Et ensuite

Quand la machine brode, tu reportes le tout sur la plaque perforée : le [plan d'implantation](plan-implantation-plaque.svg) et la [liste des liaisons](plaque-liaisons.md) décrivent exactement le même circuit, en version soudée.

Rien ne change électriquement. Tu auras simplement l'expérience du montage derrière toi.

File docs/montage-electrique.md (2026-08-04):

# Montage électrique pas à pas

Procédure progressive : à chaque étape, un test de validation avant de passer à la suivante. **Ne jamais tout brancher d'un coup** — si quelque chose ne va pas, on ne saurait pas d'où ça vient.

Outil indispensable : un **multimètre**. Sans lui, on avance à l'aveugle.

---

## 🔴 Les trois règles à ne jamais enfreindre

1. **Ne jamais débrancher un moteur pas-à-pas quand le driver est sous tension.** La coupure du courant dans les bobinages génère une surtension qui détruit le driver instantanément. Toujours couper l'alimentation avant de toucher à un connecteur moteur.

2. **Vérifier la polarité au multimètre avant chaque première mise sous tension.** Une inversion + / − détruit driver et ESP32.

3. **Ne jamais mettre 48 V sur un DM320S** (max 38 V). Repère physiquement tes deux alims — étiquette, gaine de couleur, ce que tu veux.

---

## Étape 0 — Préparation, hors tension

### 0.1 Vérifier le 74HCT245

Lis le marquage **à la loupe** sur le boîtier. Tu dois y voir `74HCT245` ou `SN74HCT245N` — **avec le T**. Un `74HC245` ne fonctionnera pas de façon fiable.

### 0.2 Régler les micro-interrupteurs des drivers

**Avant** de brancher quoi que ce soit. La table de réglage est sérigraphiée sur le boîtier de chaque driver.

| Driver | Courant | Microstepping |
|---|---|---|
| DM542 (Z) | **4,0 A** | **1/4** → 800 pas/tour |
| DM320S (X) | **1,5 A** | **1/16** → 3200 pas/tour |
| DM320S (Y1) | **1,5 A** | **1/16** |
| DM320S (Y2) | **1,5 A** | **1/16** |

Le courant est volontairement sous le nominal (4,2 A et 1,7 A) : ça réduit fortement l'échauffement sans perte de couple perceptible — tu as 33× la marge nécessaire en X/Y.

⚠️ Les **quatre** drivers doivent avoir exactement le même réglage sur les axes concernés. Un DM320S en 1/8 et les autres en 1/16 donnerait un portique Y qui se met en biais.

### 0.3 Repérer les fils moteur par paires

Sur un moteur 4 fils, il y a deux bobines. Avec le multimètre en mode continuité ou ohmmètre :

- Deux fils qui montrent une résistance faible (2,6 Ω sur tes Nema 17, 0,9 Ω sur le Nema 23) = **une bobine** → A+ et A−
- Les deux autres = la seconde bobine → B+ et B−
- Entre deux fils de bobines différentes : circuit ouvert

Note les couleurs sur un papier. Se tromper de paire fait vibrer le moteur sans qu'il tourne.

---

## Étape 1 — Alimentations seules

Rien d'autre de branché. Ni driver, ni ESP32.

**Câblage :** secteur sur chaque alim, et pour le bloc HP, dénude le câble et repère les conducteurs.

**Test :**

```
Multimètre en Volts DC, pointes sur les sorties
→ Mean Well : 48 V (±1 V)
→ Bloc HP   : 19,5 V (±0,5 V)
```

Note bien quelle borne est le **+** et laquelle est le **−**. Sur le bloc HP, le conducteur central est généralement le +, la tresse extérieure le −. **Vérifie, ne suppose pas.**

✅ **Critère :** les deux tensions sont correctes et stables, polarités identifiées et notées.

⚠️ Ces alims ont le **230 V accessible** sur leurs borniers. Couvre-les d'un capot ou d'un boîtier avant la suite, et raccorde la terre au châssis métallique.

---

## Étape 2 — ESP32 seul

Alimenté par son chargeur USB, rien d'autre de connecté.

**Actions :**

1. **Effacer entièrement la flash**, puis flasher FluidNC. Les cartes neuves arrivent souvent avec le firmware ESP-AT d'usine, dont la table de partitions empêche FluidNC de se loger correctement. Deux voies :
   - [installer.fluidnc.com](http://installer.fluidnc.com) avec Chrome ou Edge, **en cochant l'option d'effacement**
   - ou le zip `fluidnc-vX.Y.Z-win64.zip` des [releases GitHub](https://github.com/bdring/FluidNC/releases), qui contient `erase.bat` puis `install-wifi.bat` — aucun Python requis

   Choisir la version **WiFi** (pas Bluetooth ni WiFi+BT) et **WebUI v3**.

2. **Téléverser `index.html.gz`** (présent dans le zip) dans le Flash Filesystem. Sans lui, l'interface affiche seulement `File index.html.gz is missing`, sans terminal.

3. **Téléverser `firmware/fluidnc-config.yaml`**, puis lui dire de l'utiliser :

```
$Config/Filename=fluidnc-config.yaml
$Bye
```

   En v4, le nom cherché par défaut est `config.yaml` — d'où cette commande si le fichier porte un autre nom. Le réglage est mémorisé, à faire une seule fois.

4. Configurer le WiFi :

```
$Sta/SSID=TonReseau
$Sta/Password=TonMotDePasse
$WiFi/Mode=STA>AP
$Bye
```

   **`STA>AP` plutôt que `STA`** : la carte tente de rejoindre ton réseau et **retombe en point d'accès si elle échoue**. Avec `STA` seul, un mot de passe erroné te laisse sans aucun accès. L'ESP32 ne capte que le **2,4 GHz** ; `$WiFi/ListAPs` liste ce qu'il voit réellement.

**Test :**

```
$SS         → rejoue le log de démarrage, doit être exempt de MSG:ERR
$I          → doit répondre avec la version FluidNC
```

L'adresse IP attribuée par la box se lit avec `$System/Stats`. En mode point d'accès, c'est `192.168.0.1` (réseau `FluidNC`, mot de passe `12345678`).

✅ **Critère :** FluidNC répond, `$SS` affiche le nom de ta machine et 4 axes sans aucune erreur, l'interface web est accessible.

### Si le démarrage boucle ou refuse la config

| Symptôme | Cause | Correction |
|---|---|---|
| `Controller is in a reset loop` | entrée de contrôle active en continu (fil GPIO 33 en l'air, ou bouton NC) | débrancher GPIO 32/33 et retester |
| Écriture du flash interrompue à x % | câble USB de charge, hub, ou périphériques branchés sur la carte | câble data court, port direct, **carte nue** pendant le flash |
| `Wrong boot mode detected (0x13)` | l'auto-reset de la carte ne fonctionne pas | maintenir **BOOT**, appuyer sur **EN**, relâcher EN puis BOOT |
| `Line 1: Invalid character` | commentaires en `//` | les commentaires YAML s'écrivent avec `#` |
| `Expected a float value` | commentaire en **fin** de ligne | FluidNC ne les gère pas : mettre le commentaire sur sa propre ligne |
| `Cannot open configuration file` | nom de fichier différent de `config.yaml` | `$Config/Filename=...` |

---

## Étape 3 — Le 74HCT245

Toujours sans les drivers.

**Câblage :**

| Broche 245 | Vers |
|---|---|
| 20 (VCC) | +5 V |
| 10 (GND) | masse |
| 1 (DIR) | **+5 V** |
| 19 (OE) | **masse** |
| A1–A8 | GPIO de l'ESP32 (voir `cablage.md`) |

Les broches 1 et 19 sont celles qu'on oublie : sans elles, la puce reste muette.

**Test :** commande un déplacement et mesure la sortie correspondante.

```gcode
$J=G91 X10 F500
```

Multimètre sur la broche **B1** (sortie X step) : tu dois voir une tension qui varie — en moyenne quelques volts pendant le mouvement, 0 V au repos. Si tu as un oscilloscope, tu verras les impulsions.

✅ **Critère :** les sorties B basculent bien entre 0 et ~5 V quand tu commandes un jog.

❌ **Si rien ne bouge :** vérifie d'abord OE à la masse et DIR au +5 V. C'est la cause dans 90 % des cas.

---

## Étape 4 — Le premier driver, SANS moteur

On commence par l'axe X. **Le moteur reste débranché.**

**Câblage :**

```
PUL+ ← B1 (245)        PUL− → masse
DIR+ ← B2 (245)        DIR− → masse
ENA+ ← B7 (245)        ENA− → masse
V+   ← 19,5 V          GND  → masse commune
```

**Test :**

```gcode
$J=G91 X10 F500
```

Les **LED du driver** doivent réagir. La plupart des DM320S ont une LED verte (alimentation) et une rouge (défaut). La verte doit être allumée, la rouge éteinte.

✅ **Critère :** LED verte allumée, pas de LED d'erreur, aucun échauffement anormal.

---

## Étape 5 — Le premier moteur

**Coupe l'alimentation.** Branche le moteur X sur A+/A−/B+/B− selon les paires repérées à l'étape 0.3. Remets sous tension.

**Test :**

```gcode
$J=G91 X10 F500     ; doit avancer de 10 mm
$J=G91 X-10 F500    ; doit revenir
```

✅ **Critères :**

- Le moteur tourne **régulièrement**, sans à-coup ni vibration sur place
- Le chariot se déplace bien de **10 mm** (mesure au réglet !)
- Le sens correspond à ce que tu veux

**Si le moteur vibre sans tourner** → les paires de fils sont mélangées. Coupe, permute B+ et B−.

**Si le sens est inversé** → inverse `direction_pin` dans le YAML, ou permute A+ et A−.

**Si le déplacement ne fait pas 10 mm** → recalcule `steps_per_mm` :

```
steps_per_mm corrigé = 80 × (10 / distance_mesurée)
```

---

## Étape 6 — Le portique Y (les deux moteurs)

⚠️ **C'est l'étape la plus délicate du montage.**

Branche **un seul** des deux moteurs Y d'abord, teste-le comme le X. Puis branche le second.

**Test critique :**

```gcode
$J=G91 Y10 F300
```

Les deux moteurs doivent pousser le portique **dans le même sens**. S'ils se battent, tu l'entendras immédiatement — bruit sourd, portique qui force ou se met en biais.

**Si un moteur part à l'envers :** coupe l'alimentation, et **permute une seule paire de fils sur CE moteur uniquement** (A+ et A−). Ne touche pas au YAML : les deux moteurs partagent le même signal de direction.

✅ **Critère :** le portique se déplace droit, sans bruit de contrainte, et revient exactement à sa position de départ après un aller-retour.

---

## Étape 7 — L'axe Z

**Alimentation 48 V.** Vérifie trois fois que tu branches bien la Mean Well sur le DM542, pas sur un DM320S.

**Test progressif — ne démarre pas vite :**

```gcode
$J=G91 Z360 F3600      ; un tour lent (10 °/s)
$J=G91 Z3600 F18000    ; dix tours (50 °/s)
```

✅ **Critères :**

- L'arbre principal tourne, le volant en fonte suit
- Pas de perte de pas au démarrage (le volant a de l'inertie)
- Le moteur chauffe modérément, pas au point de ne plus pouvoir le toucher

**Si le moteur décroche au démarrage** → baisse `acceleration_mm_per_sec2` de l'axe Z dans le YAML. Le volant en fonte demande une montée en vitesse progressive.

---

## Étape 8 — Les capteurs

Un par un, en vérifiant l'état dans FluidNC :

```
?          ; affiche l'état des entrées (Pn:...)
```

| Capteur | GPIO | Test |
|---|---|---|
| Fin de course X | 4 | actionne-le à la main → apparaît dans `Pn:` |
| Fin de course Y | 21 | idem |
| Hall (index Z) | 22 | approche l'aimant → doit déclencher |
| Casse-fil | 32 | court-circuite à la masse → déclenche un feed hold |
| Arrêt d'urgence | 33 | idem → déclenche un reset |

⚠️ **Le capteur Hall KY-003 est unipolaire** (A3144) : il ne réagit qu'à **une seule face** de l'aimant. Si rien ne se passe, retourne l'aimant avant de conclure à une panne.

✅ **Critère :** chaque capteur apparaît et disparaît proprement dans l'état `Pn:`, sans rebond ni déclenchement fantôme.

---

## Étape 9 — Indexation de l'axe Z

C'est le réglage qui conditionne toute la précision de la broderie.

1. Tourne l'arbre à la main jusqu'au **point mort haut** de l'aiguille
2. Positionne le capteur Hall pour qu'il déclenche **exactement** à cet instant
3. Fixe-le solidement — un capteur qui bouge, c'est l'indexation perdue
4. Lance `$H` et vérifie que l'aiguille s'immobilise bien en haut

✅ **Critère :** après plusieurs `$H` successifs, l'aiguille s'arrête toujours à la même position.

---

## Étape 10 — Le servo de tension

**Alimente-le en 5 V**, pas en 3,3 V (il tire 100–250 mA).

```gcode
G0 A0     ; tension serrée
G0 A90    ; tension relâchée
```

Règle mécaniquement la position du palonnier sur la tige de débrayage, puis ajuste les angles dans `postproc/dst2gcode.py` (`servo_engaged_deg` / `servo_released_deg`).

---

## Étape 11 — Premier motif

Avant tout, les réglages machine :

- Pied à repriser monté
- Griffes d'entraînement abaissées
- Tension du fil réduite
- Tissu tendu dans le cadre, avec stabilisateur

Puis génère un G-code **très lent** :

```bash
python3 postproc/dst2gcode.py motif.dst -o motif.nc --spm 60
```

60 points/min, c'est lent exprès : tu peux suivre chaque point à l'œil et arrêter au premier problème.

Monte ensuite progressivement : **60 → 150 → 250 → 400**.

---

## Récapitulatif des points de contrôle

| Étape | Critère de réussite |
|---|---|
| 1 | 48 V et 19,5 V mesurés, polarités notées |
| 2 | FluidNC répond, interface web accessible |
| 3 | Sorties B du 245 en 5 V |
| 4 | LED driver OK, pas d'erreur |
| 5 | X se déplace de 10 mm exactement |
| 6 | Portique Y droit, sans contrainte |
| 7 | Z tourne sans décrocher |
| 8 | Tous les capteurs détectés |
| 9 | `$H` répétable à l'identique |
| 10 | Servo débraye la tension |
| 11 | Premier motif à 60 pts/min |

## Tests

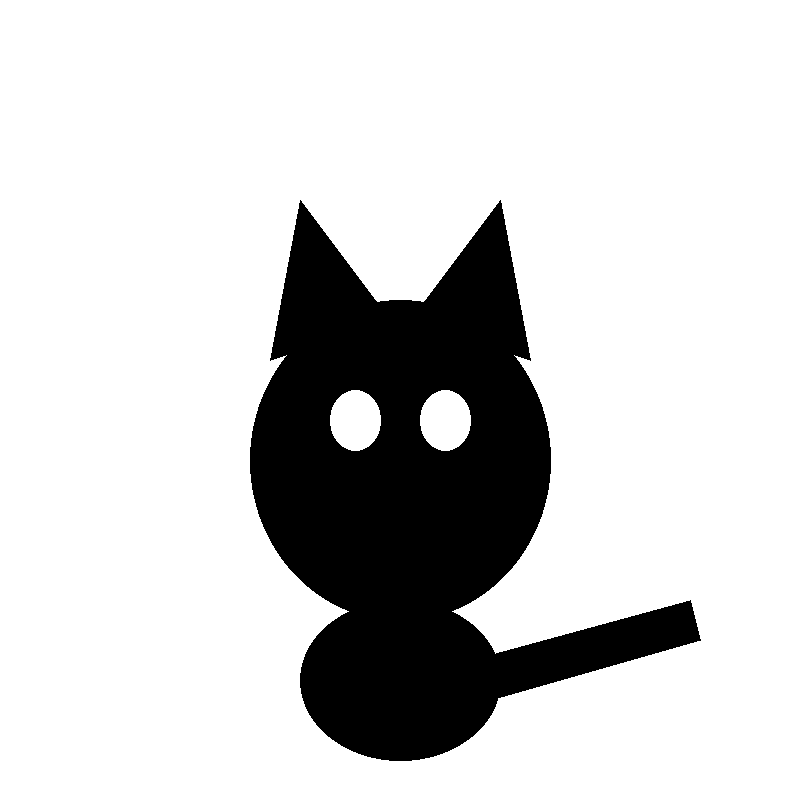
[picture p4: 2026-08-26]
postproc/tests/images/chat.png

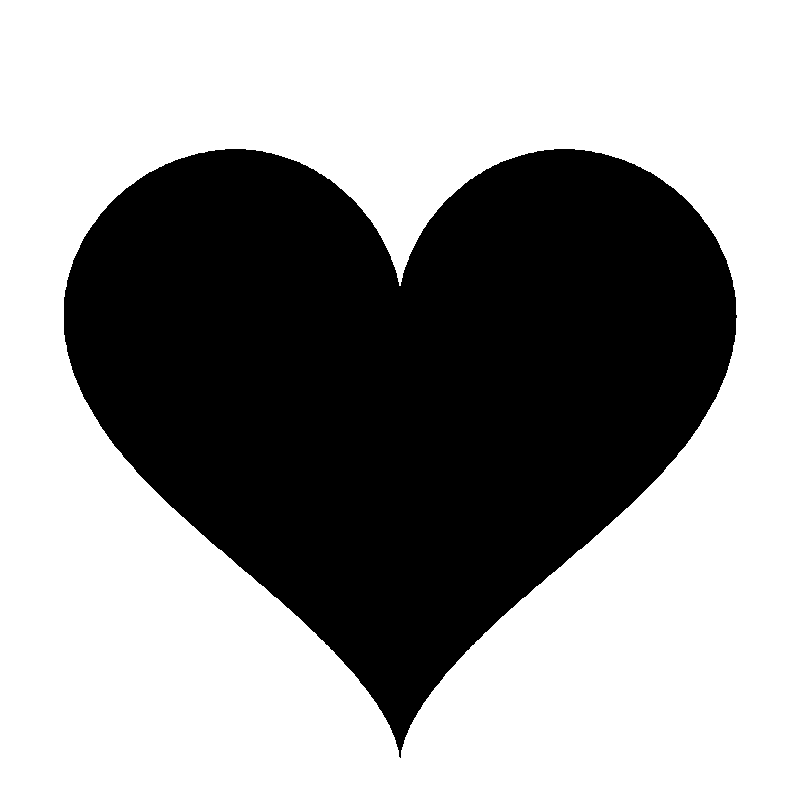
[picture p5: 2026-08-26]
postproc/tests/images/coeur.png

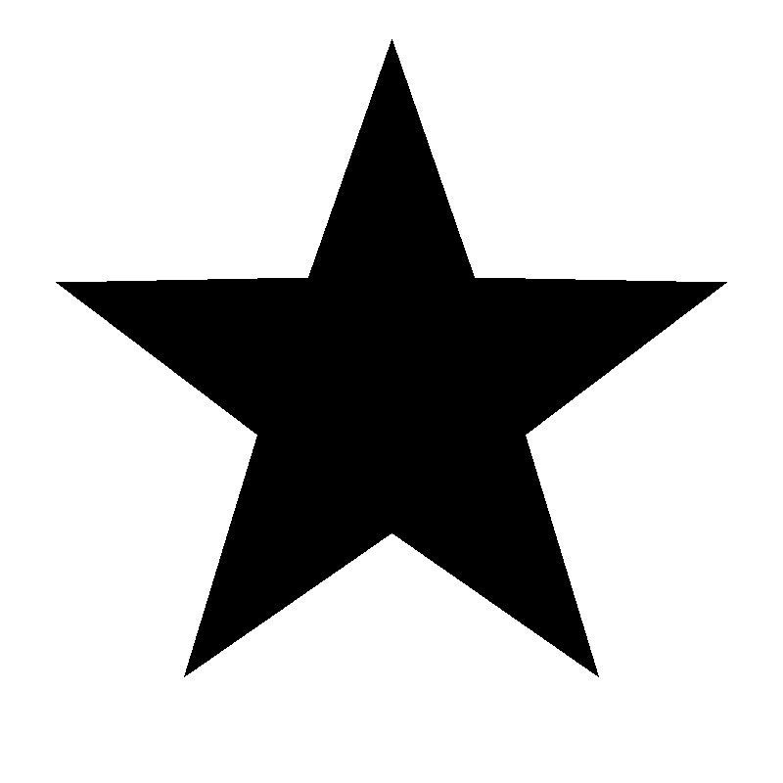
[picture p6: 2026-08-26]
postproc/tests/images/etoile.png

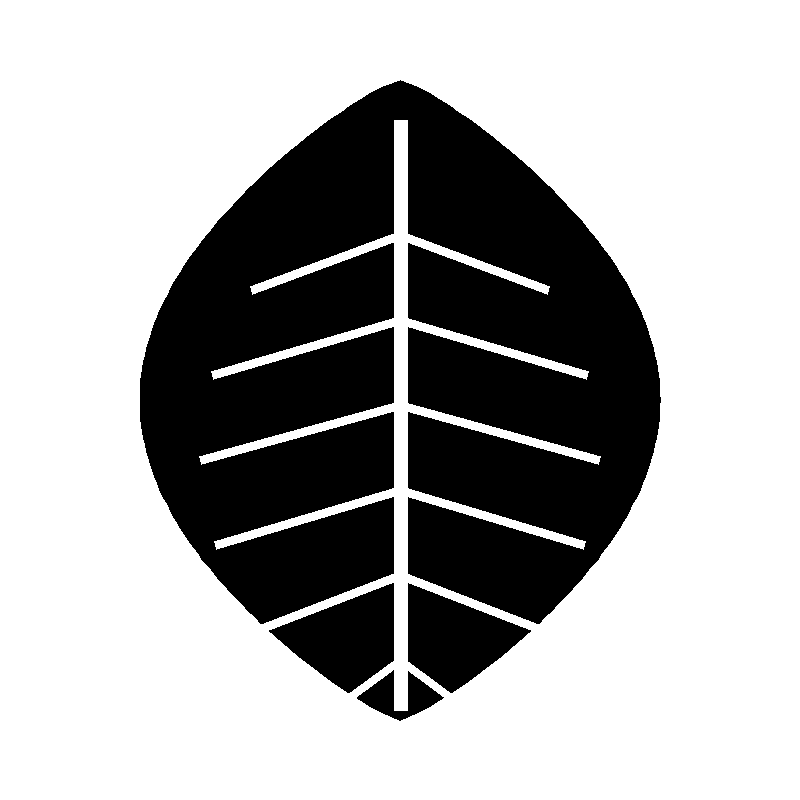
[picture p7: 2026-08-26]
postproc/tests/images/feuille.png

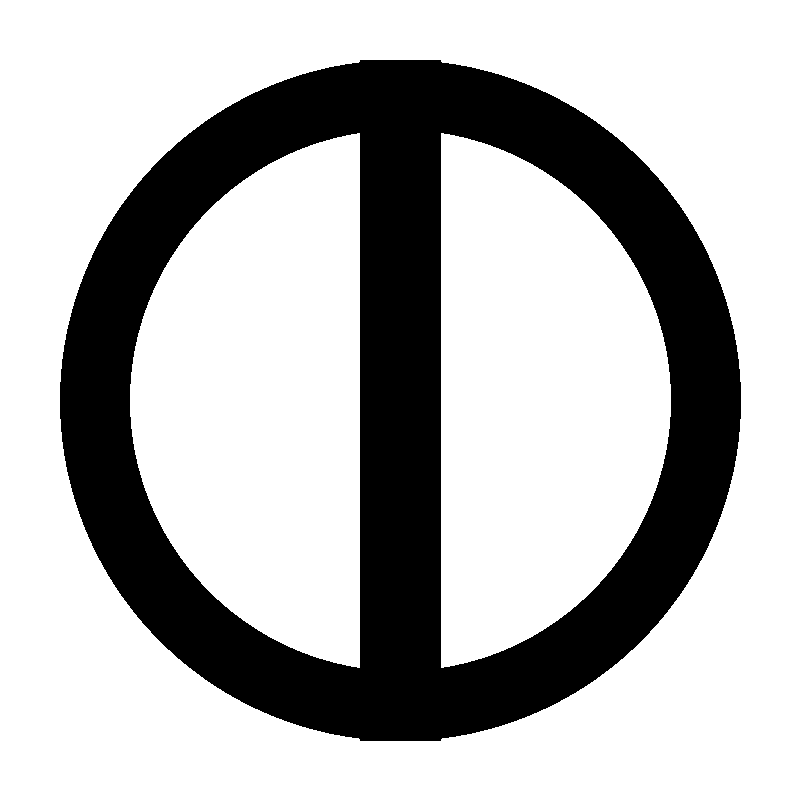
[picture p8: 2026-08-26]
postproc/tests/images/ecusson.png

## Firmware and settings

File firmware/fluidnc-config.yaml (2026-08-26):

# Brodeuse CNC Singer -- configuration FluidNC
#
# Materiel :
#   Controleur  ESP32-WROOM-32 DevKitC 38 broches (CP2102)
#   Adaptation  74HCT245 pour convertir les sorties 3,3 V en 5 V
#   Axe Z       Nema 23 3 N.m + driver DM542, alim 48 V
#   Axes X/Y    Nema 17 + drivers DM320S, alim 24 V
#
# ATTENTION -- deux alimentations distinctes sont obligatoires.
# Les DM320S acceptent 10-30 V et grilleraient en 48 V.
#
# Convention de l'axe Z : rotatif, exprime en DEGRES D'ARBRE PRINCIPAL.
#   1 point de broderie = 360 deg = 1 tour complet de l'arbre.
#   Le rapport de reduction 2:1 est absorbe par steps_per_mm ci-dessous.

name: "Brodeuse Singer CNC"
board: "ESP32 DevKitC 38 broches"

stepping:
  engine: RMT
  # 255 = les moteurs restent alimentes en permanence. Indispensable ici :
  # entre deux points, le cadre doit tenir sa position au centieme.
  idle_ms: 255
  # Les DM542/DM320S sont optocouples : il leur faut des impulsions LARGES.
  # 4 us est un point de depart sur; descends progressivement si tu veux
  # plus de vitesse, mais des pas manques viennent presque toujours d'ici.
  pulse_us: 4
  dir_delay_us: 5
  disable_delay_us: 0

# --------------------------------------------------------------------------
# Axes
# --------------------------------------------------------------------------
axes:
  # Un seul signal ENABLE partage par les quatre drivers.
  # PAS de suffixe :low. Sur les DM320S/DM542, alimenter l'optocoupleur ENA
  # DESACTIVE le driver. FluidNC doit donc mettre la ligne au niveau haut
  # pour desactiver, et au niveau bas pour activer -- c'est le comportement
  # par defaut, sans attribut.
  shared_stepper_disable_pin: gpio.13

  # ---- X ---------------------------------------------------------------
  # Nema 17, 1/16 de pas (3200 pas/tour), poulie GT2 20 dents (40 mm/tour)
  #   steps_per_mm = 3200 / 40 = 80        -> resolution 0,0125 mm
  x:
    steps_per_mm: 80.000
    # 200 mm/s
    max_rate_mm_per_min: 12000.000
    # a monter apres essais (voir docs)
    acceleration_mm_per_sec2: 3000.000
    # Course reelle mesuree le 05/08/2026 : 172 mm entre l'origine machine
    # et la butee mecanique. On retire 3 mm de marge de securite.
    max_travel_mm: 169.000
    soft_limits: true
    homing:
      cycle: 2
      positive_direction: false
      mpos_mm: 0.000
      feed_mm_per_min: 300.000
      seek_mm_per_min: 1500.000
      settle_ms: 250
      seek_scaler: 1.100
      feed_scaler: 1.100
    motor0:
      # GPIO 4 : possede un vrai pull-up interne (les 34-39 n'en ont PAS
      # et flottent -- lecon apprise en simulation Wokwi).
      limit_neg_pin: gpio.4:low:pu
      hard_limits: false
      pulloff_mm: 2.000
      standard_stepper:
        step_pin: gpio.26
        direction_pin: gpio.16

  # ---- Y (portique a DEUX moteurs) -------------------------------------
  # Le rail Y porte 2 Nema 17, un de chaque cote, pour eviter que le
  # portique se mette en biais. Leurs 2 drivers DM320S sont cables EN
  # PARALLELE sur les memes signaux Y step / Y dir : les deux moteurs
  # bougent toujours ensemble, FluidNC ne voit qu'un seul axe.
  # (Pas d'auto-equerrage : on regle la perpendicularite mecaniquement.)
  y:
    steps_per_mm: 80.000
    max_rate_mm_per_min: 12000.000
    acceleration_mm_per_sec2: 3000.000
    # Course reelle mesuree le 05/08/2026 : 121 mm, moins 3 mm de marge.
    # C'est Y qui bride le champ de broderie -- voir docs/limites-machine.md
    max_travel_mm: 118.000
    soft_limits: true
    homing:
      cycle: 2
      positive_direction: false
      mpos_mm: 0.000
      feed_mm_per_min: 300.000
      seek_mm_per_min: 1500.000
      settle_ms: 250
      seek_scaler: 1.100
      feed_scaler: 1.100
    motor0:
      limit_neg_pin: gpio.21:low:pu
      hard_limits: false
      # 5 mm et pas 2 : avec 2 mm le levier du microrupteur restait enfonce
      # apres le degagement -> ALARM:8 Homing Fail Pulloff.
      pulloff_mm: 5.000
      standard_stepper:
        step_pin: gpio.25
        direction_pin: gpio.27:low

  # ---- Z (rotatif) -----------------------------------------------------
  # Nema 23, 1/4 de pas (800 pas/tour moteur), reduction 2:1
  #   800 x 2 = 1600 pas par tour d'arbre principal
  #   steps_per_mm = 1600 / 360 = 4,4444 pas par degre
  #
  # Pourquoi 1/4 et pas 1/16 : a 400 points/min et 2:1, le moteur tourne a
  # 800 tr/min. En 1/16 cela ferait 42 700 pas/s. En 1/4 on tombe a
  # 10 700 pas/s, tres confortable. Z n'a aucun besoin de resolution fine.
  z:
    steps_per_mm: 4.4444
    # 600 deg/s = 600 points/min
    max_rate_mm_per_min: 216000.000
    # volant en fonte : montee en vitesse douce
    acceleration_mm_per_sec2: 2000.000
    # 720 deg = 2 tours d'arbre. Comme soft_limits est false, cette valeur ne
    # bride PAS la rotation : elle sert uniquement de garde-fou au homing.
    # Si l'aimant passe devant le Hall sans etre vu, FluidNC abandonne au bout
    # de deux tours au lieu de faire tourner l'arbre indefiniment.
    max_travel_mm: 720.000
    soft_limits: false
    homing:
      # Indexation sur le capteur Hall : amene l'aiguille au point mort haut.
      # Se fait EN PREMIER, avant tout mouvement du cadre.
      cycle: 1
      positive_direction: true
      mpos_mm: 0.000
      # 10 deg/s, lent et precis
      feed_mm_per_min: 3600.000
      # 50 deg/s
      seek_mm_per_min: 18000.000
      settle_ms: 500
      seek_scaler: 1.000
      feed_scaler: 1.000
    motor0:
      # Capteur Hall KY-003 + aimant neodyme 5x2 mm dans la grande poulie.
      # Sortie a collecteur ouvert -> pull-up interne (GPIO 22 en possede un).
      limit_pos_pin: gpio.22:low:pu
      hard_limits: false
      # 10 deg de degagement, valide sur machine le 05/08/2026.
      # 5 deg ne suffisaient pas : l'aimant restait dans le champ du capteur
      # Hall apres le degagement -> ALARM:8 Homing Fail Pulloff.
      # Si l'alarme revient un jour sur Z, c'est ici qu'il faut monter.
      pulloff_mm: 10.000
      standard_stepper:
        step_pin: gpio.17
        # Suffixe :low ajoute le 06/08/2026. L'arbre tournait a l'envers :
        # l'aiguille montait et descendait normalement, mais le crochet
        # passait au mauvais moment et ne saisissait jamais la boucle du fil
        # du haut. Aucun point ne se formait, sans qu'aucune erreur ne
        # s'affiche. Sur une machine a coudre, le volant tourne VERS SOI.
        direction_pin: gpio.14:low

  # ==========================================================================
  # DESACTIVE POUR L'INSTANT -- axe A : servo de debrayage de la tension
  # ==========================================================================
  # Le servo n'est pas encore installe : on ne sait pas ou le fixer sur la
  # machine. La machine tourne donc en 3 axes (X, Y, Z).
  #
  # Pour le reactiver : enlever le '#' devant les lignes ci-dessous, verifier
  # que GPIO 18 est libre, televerser et $Bye.
  #
  # Role : un petit servo (SG90/MG90S) pousse la tige de debrayage des disques
  # de tension de la Singer. Pendant un gros saut, on relache la tension pour
  # que le fil se devide librement sans casser ni tirer le tissu.
  #   A0  = tension serree (repos, position broderie)
  #   A90 = tension relachee (pendant le saut)
  #
  # a:
  #   steps_per_mm: 1.000
  #   max_rate_mm_per_min: 6000.000
  #   acceleration_mm_per_sec2: 5000.000
  #   max_travel_mm: 90.000
  #   soft_limits: false
  #   motor0:
  #     rc_servo:
  #       pwm_hz: 50
  #       output_pin: gpio.18
  #       min_pulse_us: 1000
  #       max_pulse_us: 2000

# ==========================================================================
# DESACTIVE POUR L'INSTANT -- entrees de controle
# ==========================================================================
# Ni le detecteur de casse-fil ni le bouton d'arret d'urgence ne sont encore
# installes. Les declarer alors que les fils ne sont pas cables ferait flotter
# les entrees et provoquerait des declenchements fantomes -- voire le fameux
# "Controller is in a reset loop" sur GPIO 33.
#
# Pour reactiver : enlever le '#', APRES avoir cable les capteurs.
#
# control:
#   # Detecteur de casse-fil : roue libre sur le trajet du fil + capteur Hall.
#   # Si le fil ne defile plus, la machine se met en pause.
#   feed_hold_pin: gpio.32:low:pu
#   # Arret d'urgence : bouton coup-de-poing, contact NO vers la masse.
#   reset_pin: gpio.33:low:pu
#
# GPIO 18, 32 et 33 sont donc libres pour le moment.
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

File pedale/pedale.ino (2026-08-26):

/*
 * Pedale de la brodeuse Singer -- croquis Arduino Uno
 * ===================================================
 *
 * Lit un potentiometre solidaire de la pedale d'origine et envoie sa
 * position au PC par le port serie USB.
 *
 * CABLAGE
 *   potentiometre 10 kOhm lineaire
 *     extremite 1 -> 5V
 *     curseur     -> A0
 *     extremite 3 -> GND
 *
 *   Le 5 V ne pose aucun probleme ici : l'ADC de l'Uno est prevu pour.
 *   C'est sur l'ESP32 qu'il serait destructeur.
 *
 * PROTOCOLE
 *   Une ligne par mesure, envoyee seulement quand la valeur CHANGE :
 *     P0     pedale relachee
 *     P1..P100  pourcentage d'enfoncement
 *   Plus une ligne "PING" toutes les secondes, meme a l'arret.
 *
 *   Le PING est le coeur de la securite : c'est lui qui prouve que la
 *   pedale est toujours la. Si le PC cesse de le recevoir -- cable
 *   debranche, Uno plante --, il arrete la machine. Sans ce battement,
 *   une pedale muette serait indistinguable d'une pedale au repos.
 *
 * ATTENTION
 *   La pedale Singer d'origine commute du 230 V. Elle doit etre
 *   TOTALEMENT deconnectee du secteur. Seul le potentiometre, mecaniquement
 *   solidaire de sa course, est relie a l'Uno.
 */

const uint8_t BROCHE_PEDALE = A0;

// Zone morte en debut de course. Un potentiometre ne revient jamais
// exactement a zero, et une pedale au repos ne doit RIEN faire.
const int SEUIL_BAS = 450;      // sur 1023

// Marge en fin de course : on atteint 100 % avant la butee mecanique,
// pour ne pas dependre du dernier millimetre.
const int SEUIL_HAUT = 1010;

// Filtre passe-bas ASYMETRIQUE. Le cable de la pedale passe pres des
// drivers, qui rayonnent : sans lissage, la consigne tremblerait.
// Mais le relachement est un ordre d'arret : il doit passer vite.
//   montee  : douce, filtre le bruit
//   descente : franche, l'arret est detecte en un ou deux cycles
const float LISSAGE_MONTEE = 0.25;
const float LISSAGE_DESCENTE = 0.65;

// Hysteresis : on n'emet que si la valeur bouge d'au moins ce pourcentage.
// Evite d'inonder le port serie pour du bruit.
const int PAS_MINIMAL = 2;

const unsigned long PERIODE_PING_MS = 1000;
const unsigned long PERIODE_LECTURE_MS = 20;

float valeur_lissee = 0.0;
int dernier_envoye = -1;
unsigned long dernier_ping = 0;
unsigned long derniere_lecture = 0;

void setup() {
  Serial.begin(115200);
  // Premiere lecture sans lissage, pour ne pas partir de zero si la
  // pedale est deja enfoncee au branchement.
  valeur_lissee = analogRead(BROCHE_PEDALE);
  Serial.println(F("PEDALE v1"));
}

int versPourcentage(float brut) {
  if (brut <= SEUIL_BAS) return 0;
  if (brut >= SEUIL_HAUT) return 100;
  return (int)((brut - SEUIL_BAS) * 100.0 / (SEUIL_HAUT - SEUIL_BAS));
}

void loop() {
  unsigned long maintenant = millis();

  if (maintenant - derniere_lecture >= PERIODE_LECTURE_MS) {
    derniere_lecture = maintenant;

    int brut = analogRead(BROCHE_PEDALE);
    float lissage = (brut < valeur_lissee) ? LISSAGE_DESCENTE : LISSAGE_MONTEE;
    valeur_lissee += (brut - valeur_lissee) * lissage;
    int pourcent = versPourcentage(valeur_lissee);

    // Le retour a zero est TOUJOURS transmis, sans hysteresis : c'est un
    // ordre d'arret, il ne doit jamais etre retenu par un filtre.
    bool changement = (pourcent == 0 && dernier_envoye != 0)
                   || (abs(pourcent - dernier_envoye) >= PAS_MINIMAL);

    if (changement) {
      Serial.print('P');
      Serial.println(pourcent);
      dernier_envoye = pourcent;
      dernier_ping = maintenant;
    }
  }

  if (maintenant - dernier_ping >= PERIODE_PING_MS) {
    dernier_ping = maintenant;
    Serial.println(F("PING"));
  }
}

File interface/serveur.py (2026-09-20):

#!/usr/bin/env python3
# -*- coding: utf-8 -*-
"""
Serveur local pour la brodeuse CNC Singer.

    python serveur.py
    puis http://localhost:8080

TOUT PASSE PAR USB. Le G-code reste sur le PC et part ligne par ligne vers
la carte : la memoire de l'ESP32 n'intervient plus, et le WiFi n'est plus
dans la boucle de commande. Une pedale progressive, lue par un Arduino Uno,
pilote le mode couture.

    pedale -> potentiometre -> Uno --USB--> PC --USB--> ESP32 -> machine
"""

from __future__ import annotations

import argparse
import re
import sys
import time
from pathlib import Path

try:
    from flask import Flask, Response, jsonify, request, send_from_directory
except ImportError:
    sys.exit("Flask manquant.  ->  python -m pip install flask")

sys.path.insert(0, str(Path(__file__).resolve().parent.parent / "postproc"))
try:
    import dst2gcode
    import image2points
except ImportError as e:
    sys.exit("Modules de conversion introuvables (%s).\n"
             "Verifie que postproc/ est a cote de interface/, et que pillow, "
             "numpy et opencv-python-headless sont installes." % e)

from couture_pedale import CoutureAPedale, cadence_depuis_pedale  # noqa: E402
from envoi import Envoyeur                                        # noqa: E402
from liaison import (Fluid, Pedale, deviner, identifier_tous,     # noqa: E402
                     lister_ports)


# ---------------------------------------------------------------------------
# Reglages machine
# ---------------------------------------------------------------------------

# Champ de broderie utile, en mm (voir docs/limites-machine.md).
CADRE_X = 165.0
CADRE_Y = 114.0

# Centre du champ en coordonnees machine : origine piece posee la.
CENTRE_X = 84.5
CENTRE_Y = 59.0

# Parcage du cadre en mode couture.
PARK_X = 84.5
PARK_Y = 5.0

# Decalage entre le capteur Hall et le point mort haut reel de l'aiguille,
# en degres d'arbre. Propriete de LA MACHINE, pas du motif.
#
# A mesurer une fois pour toutes :
#   $HZ                    homing de Z, l'aiguille s'arrete au capteur
#   $J=G91 Z10 F1800       par paliers, jusqu'au point mort haut exact
#   ?                      MPos Z donne la valeur a reporter ici
#
# Tant qu'il est faux, le cadre se deplace au mauvais moment du cycle :
# l'aiguille flechit, les points sautent, et le fil finit par casser.
DECALAGE_PHASE_Z_DEG = -29.0

DOSSIER_SORTIE = Path(__file__).resolve().parent.parent / "gcode"

RE_ETAT = re.compile(r"<([A-Za-z]+)[|:]")
RE_MPOS = re.compile(r"MPos:([-\d.]+),([-\d.]+),([-\d.]+)")


# ---------------------------------------------------------------------------
# Etat du serveur
# ---------------------------------------------------------------------------

class Machine:
    """Tout ce qui est branche, au meme endroit."""

    def __init__(self) -> None:
        self.fluid: Fluid | None = None
        self.pedale: Pedale | None = None
        self.envoyeur: Envoyeur | None = None
        self.couture: CoutureAPedale | None = None
        self.erreur = ""
        # Dernier port demande pour la pedale. Retenu pour pouvoir la
        # rebrancher seule, sans rouvrir le port de la carte -- ce qui
        # provoquerait un reset de l'ESP32 et une alarme.
        self.port_pedale = ""

    @property
    def connectee(self) -> bool:
        return bool(self.fluid and self.fluid.connecte)

    def connecter(self, port_fluid: str, port_pedale: str | None) -> str:
        self.deconnecter()
        try:
            self.fluid = Fluid(port_fluid)
            self.fluid.ouvrir()
        except Exception as e:                       # noqa: BLE001
            self.fluid = None
            return "Carte injoignable sur %s : %s" % (port_fluid, e)

        self.envoyeur = Envoyeur(self.fluid)

        if port_pedale:
            self.port_pedale = port_pedale
            if (erreur := self.connecter_pedale()):
                return "Carte connectee, mais " + erreur
        return ""

    def connecter_pedale(self, port: str | None = None) -> str:
        """Ouvre la pedale seule. Rend un message d'erreur, ou une chaine vide.

        Separe de connecter() a dessein : rebrancher la pedale ne doit pas
        toucher au port de la carte. Rouvrir ce dernier reinitialise l'ESP32,
        ce qui remet la machine en alarme et impose un nouveau homing --
        inacceptable pour recuperer un simple cable debranche.
        """
        if not self.fluid:
            return "carte non connectee."

        port = port or self.port_pedale
        if not port:
            return "aucun port connu pour la pedale."

        if self.couture:
            self.couture.arreter()
        if self.pedale:
            self.pedale.fermer()
        self.pedale = self.couture = None

        try:
            pedale = Pedale(port)
            pedale.ouvrir()
        except Exception as e:                       # noqa: BLE001
            # La pedale est un confort : son absence ne doit jamais empecher
            # de broder.
            return "pedale injoignable sur %s : %s" % (port, e)

        self.port_pedale = port
        self.pedale = pedale
        self.couture = CoutureAPedale(self.fluid, pedale)
        return ""

    def deconnecter(self) -> None:
        if self.couture:
            self.couture.arreter()
        if self.pedale:
            self.pedale.fermer()
        if self.fluid:
            self.fluid.fermer()
        self.fluid = self.pedale = self.envoyeur = self.couture = None


machine = Machine()
motif_courant: dict = {}


# ---------------------------------------------------------------------------
# Application
# ---------------------------------------------------------------------------

RACINE = Path(__file__).resolve().parent
app = Flask(__name__, static_folder=None)


@app.errorhandler(Exception)
def toute_erreur(e):
    """Aucune exception ne doit rendre l'interface muette.

    Une page qui affiche « serveur hors ligne » sur une erreur de port serie
    fait chercher le probleme au mauvais endroit. On repond toujours du JSON
    exploitable.
    """
    app.logger.exception("Erreur non rattrapee")
    return jsonify({"ok": False, "connectee": machine.connectee,
                    "erreur": "%s : %s" % (type(e).__name__, e)}), 500


@app.get("/")
def page_broderie() -> object:
    return send_from_directory(RACINE / "static", "broderie.html")


@app.get("/couture")
def page_couture() -> object:
    return send_from_directory(RACINE / "static", "index.html")


# ---- connexion -----------------------------------------------------------

@app.get("/api/ports")
def api_ports() -> object:
    return jsonify({
        "ports": lister_ports(),
        "suggestion_fluidnc": deviner("fluidnc"),
        "suggestion_pedale": deviner("pedale"),
        "connectee": machine.connectee,
    })
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

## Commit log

2026-07-21 Structure initiale : post-processeur DST vers G-code, config FluidNC, documentation
    [fluidnc-config.yaml]
2026-07-23 Portique Y a 2 moteurs, capteurs sur pins pull-up interne, alim 24V, simulation Wokwi
    [fluidnc-config.yaml]
2026-07-23 Servo de tension du fil pour les sauts longs, passage en WiFi, schema de cablage
    [fluidnc-config.yaml]
2026-08-04 Schema electronique complet avec alimentations, guide de montage, mise a jour FluidNC v4
    - docs/schema-electronique-complet.svg : distribution 230 V (interrupteur bipolaire,
    fusible T 2 A, terre de protection), les trois alimentations, chaine de commande,
    capteurs, arret d'urgence, servo et barre de masse commune
    - docs/montage-electrique.md : procedure pas a pas avec un critere de validation par etape
    - Etape 2 revue d'apres le montage reel : effacement de la flash avant de flasher FluidNC,
    upload de index.html.gz, $Config/Filename, mode WiFi STA>AP, et un tableau des erreurs
    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
    [fluidnc-config.yaml, plaque_renvoi.dxf, plaque_renvoi_x6.dxf]
2026-08-04 Decoupe le schema en quatre vues lisibles et ajoute la table de cablage
    Le schema unique etait trop dense : fils qui se chevauchent, connexions
    illisibles. Remplace par un schema par sous-ensemble, chacun sans croisement,
    et par une table exhaustive fil par fil.
    - schema-1-alimentations : secteur, protections, terre, les trois alims
    - schema-2-logique : brochage reel du DIP-20 du 74HCT245
    - schema-3-puissance : les quatre drivers borne par borne
    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
2026-08-04 Plan d'implantation de la carte de commande sur plaque perforee
    - plan-implantation-plaque.svg : vue de dessus d'une grille 32 x 30 trous avec
    l'ESP32 sur barrettes, le support DIP-20 du 74HCT245, les connecteurs J1 et J2,
    les bus 0 V et +5 V, et le trace des 34 liaisons cote soudure
    - plaque-liaisons.md : chaque fil avec ses coordonnees (colonne, rangee), le
    brochage des connecteurs, l'ordre de montage et les verifications au multimetre
    a faire avant d'inserer les composants
    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
2026-08-04 Montage sur platine d'essai, sans soudure, avant la version definitive
    Valider toute la chaine avant de souder : le 74HCT245 seul sur une demi-platine,
    l'ESP32 a cote relie par cavaliers Dupont, les capteurs directement sur ses broches.
    - plan-platine-essai.svg : implantation trou par trou sur la platine
    - montage-platine-essai.md : pas a pas, avec le fonctionnement d'une platine
    d'essai pour qui n'en a jamais utilise, et les verifications avant mise sous
    tension
    - cablage.md : les deux versions de la carte sont maintenant presentees dans
    l'ordre — platine d'essai d'abord, plaque perforee ensuite
2026-08-05 Corrige la doc sur les masses et desactive ce qui n'est pas encore installe
    Masses -- correction d'une erreur de documentation. Les entrees des DM320S et
    du DM542 sont optocouplees : le 0 V logique (ESP32, 245, capteurs, PUL- DIR-
    ENA-) et le 0 V puissance (les "-" des alims, bornes GND des drivers) sont
    deux reseaux isoles. Rien n'oblige a les relier, contrairement a ce qu'affirmait
    la doc. Schemas 1 et 3 et table de cablage repris en consequence.
    Materiel pas encore installe -- mis en commentaire plutot que supprime :
    - axe A (servo de tension) : emplacement sur la machine pas encore trouve
    - control: feed_hold (casse-fil) et reset (arret d'urgence) : capteurs absents
    - Une entree declare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
    [fluidnc-config.yaml]
2026-08-26 Corrige l'annulation bloquante, la latence de lecture serie, et ajoute le deploiement Docker
    [fluidnc-config.yaml]
2026-08-26 Ajoute Pillow, oublie dans l'audit des dependances
2026-08-26 Pedale : jogs et annulation 0x85, la vitesse ne survit plus au relachement
2026-08-26 Pedale : decoupage en tranches de 50 ms, la vitesse mord sans attendre la fin du point
2026-08-26 Le redeployeur repart toujours d'un depot propre avant de tirer
2026-08-26 Debrayage du volant a l'arret, desormais fiable grace au vidage de file
2026-08-30 Rebranchement de la pedale seule, et reglage des accelerations depuis l'interface
2026-08-30 Pedale : comptage de caracteres, le tampon de la carte ne deborde plus (error:9)
    [couture_pedale.py]
2026-09-20 Annonce la nature de chaque pause, et les couleurs a monter
2026-09-20 Recentre automatiquement les motifs deja numerises sur le cadre
2026-09-20 Distingue clairement les pauses de couleur, reglage de la pause de pied
2026-09-20 Synchronise l'apercu avec le vrai seuil de traversee brodee
2026-11-07 Revue broderie + compensation de flexion du cadre avec motif de calibration
2026-11-07 Calibration : bandes reperees par le sens des points, mesure de pointe a pointe
2026-11-08 Calibration : flexion seule depuis la bande etroite, sans piege sur la bande longue
